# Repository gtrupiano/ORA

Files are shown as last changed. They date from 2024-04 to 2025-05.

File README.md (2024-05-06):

# Oakland Robotics Association (ORA)

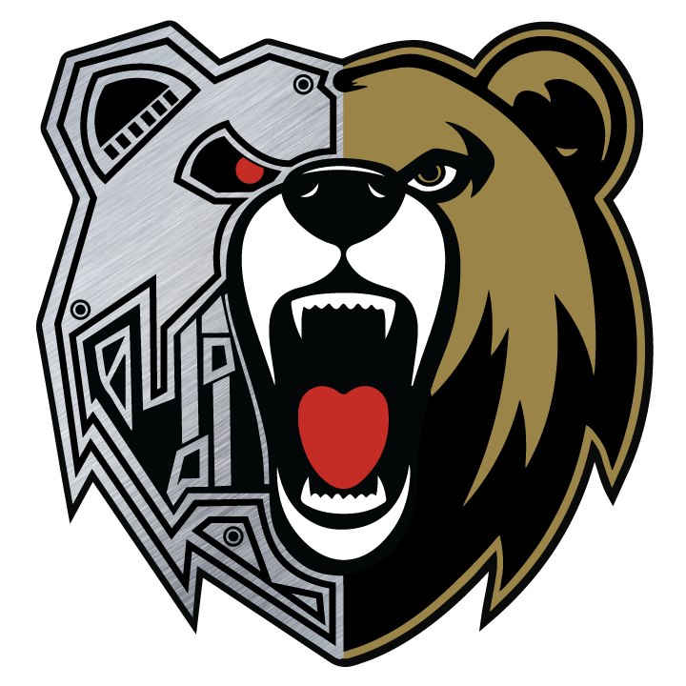
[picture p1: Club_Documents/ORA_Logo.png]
ORA


## IGVC
Each year, Robotics Association at Oakland University competes in the International Ground Vehicle
Competition (IGVC), specifically the IGVC auto-nav challenge. To compete, a fully autonomous
unmanned ground robotic vehicle needs to be design to travel around an outdoor obstacle course under a
prescribed time while maintaining certain speed constraints. The 2024 IGVC will take place at OU on
5/31/2024-6/3/2024. The Robotics Association will design a completely new robot for this year’s
competition.

### Electrical Subteam Requirements
The project looks to design, implement, and provide documentation for the electrical subsystem of the 2024
International Ground Vehicle Competition (IGVC) intelligent robotic platform. The project team will
interface with both mechanical and software subsystem teams to ensure smooth integration of the developed
electrical subsystem into the main robot. The electrical subsystem will include sensors (such as initial
measurement units, global positioning system, camera, etc.), motors, low-level controllers (such as
Arduino), power distribution system (including batteries, battery management systems, power converters,
etc.), LED display, and safety functions (such as emergency stops, fuses, and light indication). The project
will also involve detailed documentation and a final report that can be integrated into the IGVC final report.

## Components and Layout

### Control Board
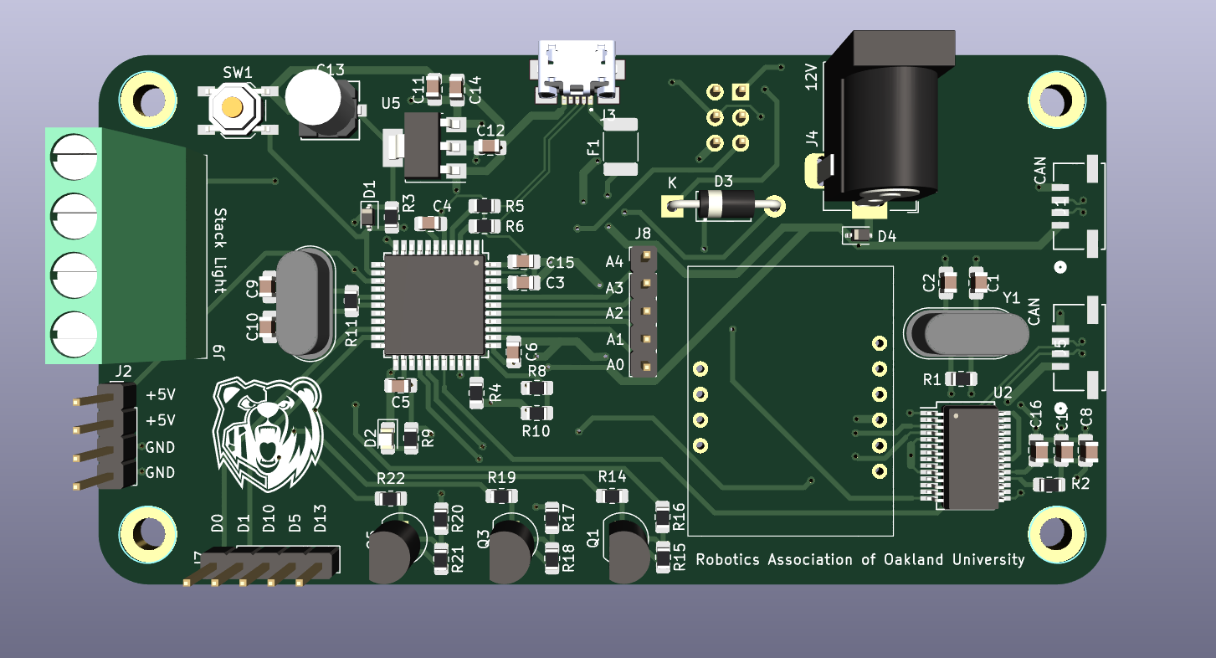
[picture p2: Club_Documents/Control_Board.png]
Control_Board


In the robot, there were plenty of components that needed to interface together. These include both ODrives over CAN and status light control. Its main purpose is to reduce the amount of wires that need to be going from each component and have every necessary component on a single board.

### Robot Control Layout
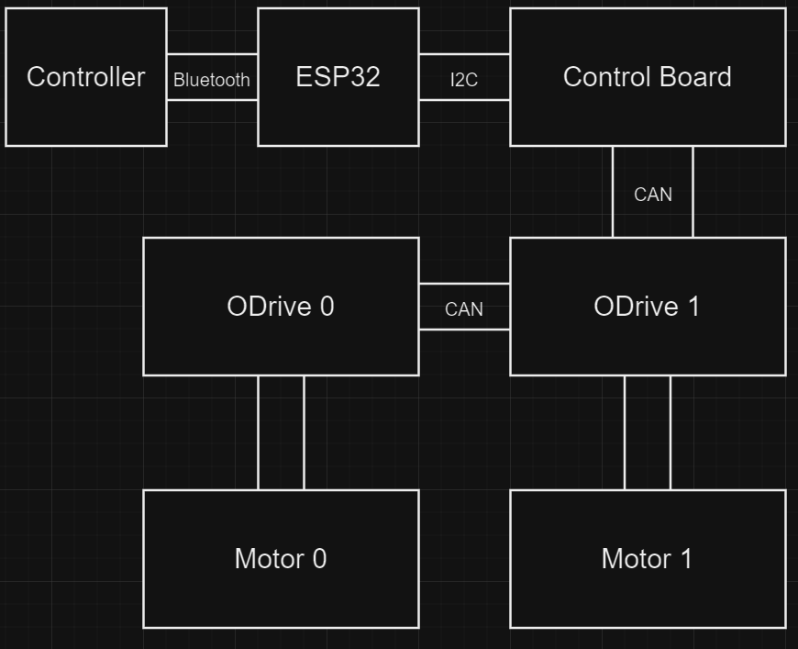
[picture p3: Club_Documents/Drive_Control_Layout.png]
Drive_Control


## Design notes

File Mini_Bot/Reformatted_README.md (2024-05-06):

# Oakland Robotics Association (ORA)

ORA Logo

## IGVC Competition Overview

Each year, the Robotics Association at Oakland University takes part in the International Ground Vehicle Competition (IGVC), focusing on the auto-nav challenge. In this competition, teams are tasked with designing a fully autonomous unmanned ground robotic vehicle capable of navigating an outdoor obstacle course within a set timeframe, while adhering to specified speed constraints. The 2024 IGVC is scheduled to be held at Oakland University from May 31 to June 3, 2024. Our team will develop an entirely new robot for this year's challenge.

### Electrical Subteam Goals

For the 2024 competition, our goal is to design, implement, and document the electrical subsystem of our intelligent robotic platform. This will involve collaboration with the mechanical and software subteams to ensure that the electrical components integrate seamlessly. The subsystem will feature a variety of components, including:
- Sensors (e.g., IMUs, GPS, cameras)
- Motors
- Low-level controllers (e.g., Arduino)
- Power distribution system (batteries, BMS, power converters, etc.)
- LED display
- Safety features (emergency stops, fuses, light indicators)

Detailed documentation and a comprehensive final report will be prepared to integrate into the IGVC final report.

## Design Components and Layout

### Control Board Overview

Control Board

The Control Board is designed to streamline the connections between various components, reducing the complexity of wiring and enhancing overall efficiency. Key features include integration of ODrives over CAN for motor control and management of the status light system. The board centralizes connections, making it easier to manage and troubleshoot the system.

### Robot Control Layout

Robot Drive Control Layout

This layout illustrates the schematic organization of the robot's driving and control systems. It highlights how different components interconnect and function together to provide optimal control and performance during competition.

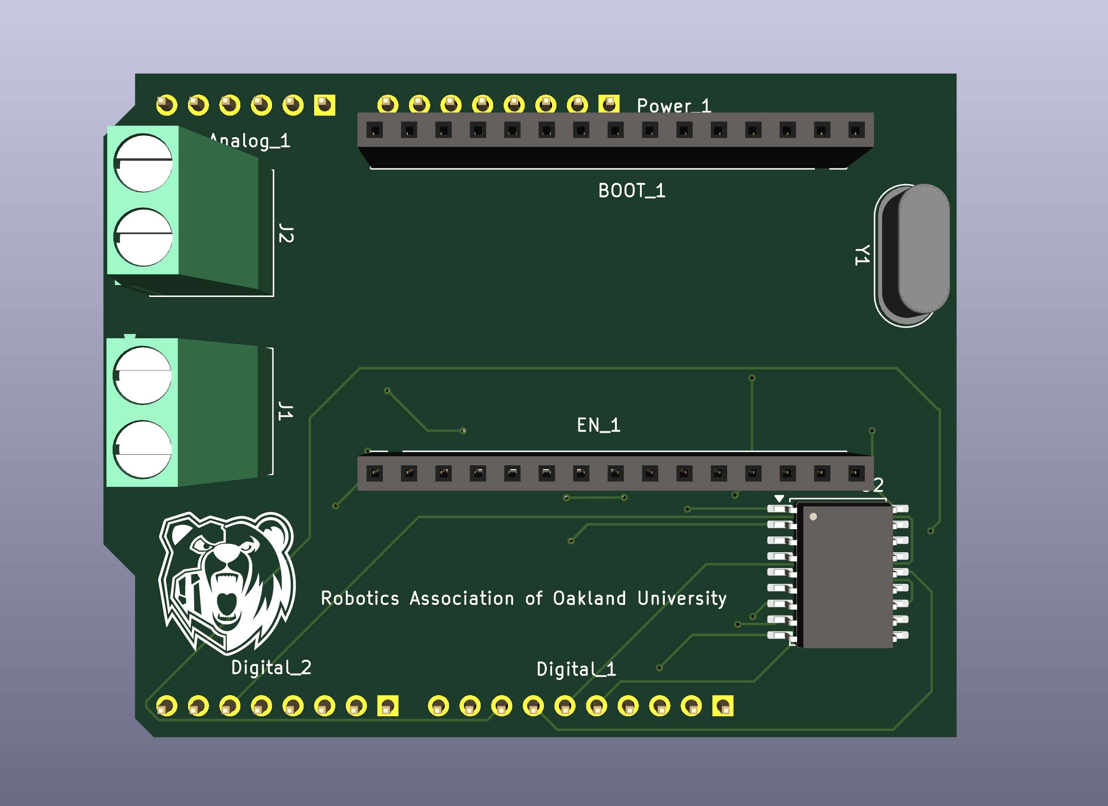
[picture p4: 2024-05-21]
Club_Documents/ESP_CAN_Shield_Front.png

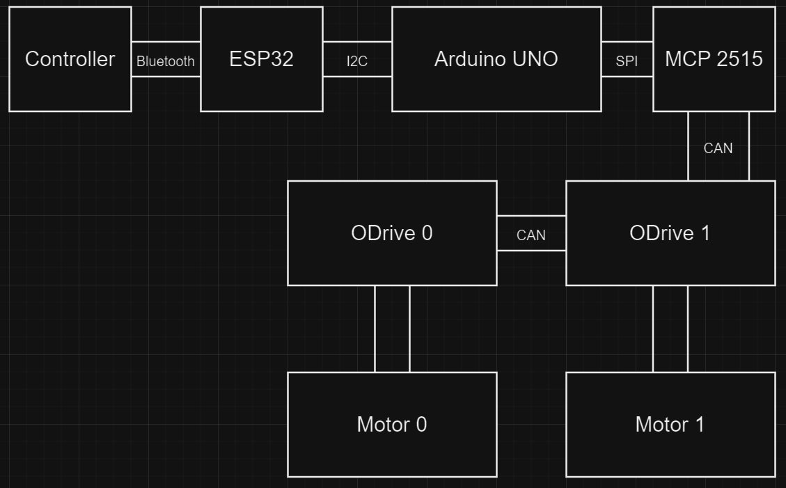
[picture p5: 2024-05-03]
Club_Documents/Drive_Control_Layout_Demo.png

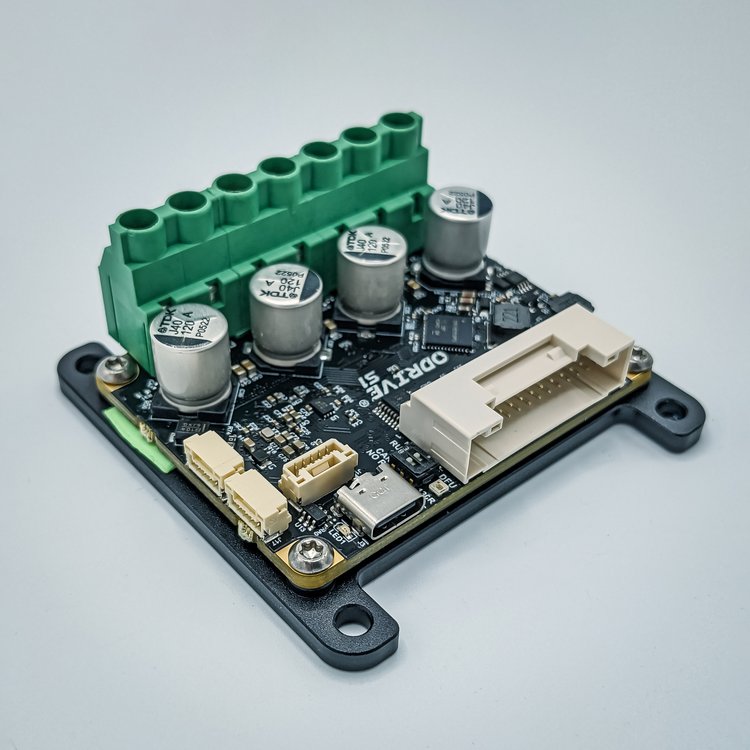
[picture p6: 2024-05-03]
Club_Documents/ODrive_S1.jpg

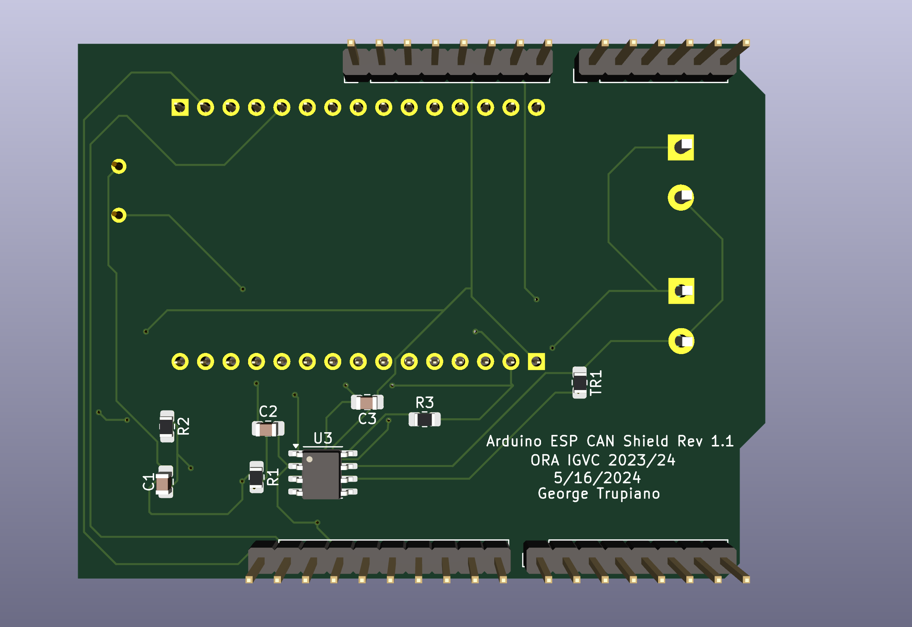
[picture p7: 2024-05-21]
Club_Documents/ESP_CAN_Shield_Back.png

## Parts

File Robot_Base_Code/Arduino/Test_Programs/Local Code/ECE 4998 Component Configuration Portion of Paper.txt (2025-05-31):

Since there are a variety of different components in Horizon, properly controlling each one is something that needs to be properly addressed. 

Components including each ODrive, CAN Communication with ODrive, Control Board, and Stack Light. Each component has both a software and hardware (wiring) aspect to it. 

ODrive
When configuring the ODrives, there were different perameters within the ODrive that needed to be configured. These include power, motor, control mode, and communication parameters.

	Power:
Configurations for the power supply needed to be modified based on the battery present on Horizon. Specifying the maximum and minimum voltage expected from the battery. This is used in order for the Odrive to check whtether it is being over or under volted and disengage when limits are crossed. 

Matching the specifications of the battery to the parameters, the maximum and minimum voltage shouldn't cross 17V and 12V respectivly. A maximum positive current is also needed to make sure the ODrive isn't drawing more current then possible from the battery which in this case is 30A.

	Motor:
Setting the motor parameters is needed to make sure the ODrives don't draw too much current from the battery. The parameters that are needed consist of pole pairs, KV, and current limit.

	Control Mode:
dsfaasdf

	Communication:
asdfasdf

CAN Communication with ODrive:

	Intro:
kjhgkjh

Connecting CAN signals to ODrive
ODriveArduino

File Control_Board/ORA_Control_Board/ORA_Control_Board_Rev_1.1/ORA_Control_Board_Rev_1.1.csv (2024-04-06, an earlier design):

Source: | C:\Users\sivas\Documents\Robotics\ORA_ControlBoard-main\ORA_ControlBoard-main\ORA_CONTROLBOARD_REV1\ORA_CONTROLBOARD_REV1.kicad_sch
Date: | 1/13/2024 3:55:22 PM
Tool: | Eeschema 7.0.8
Generator: | C:\Program Files\KiCad\7.0\bin\scripting\plugins/bom_csv_grouped_by_value_with_fp.py
Component Count: | 69
Ref | Qnty | Value | Cmp name | Footprint | Description | Vendor | DNP
C1, C2, C9, C10, C13 | 5 | 22uF | C_Polarized_Small | Capacitor_SMD:C_0805_2012Metric_Pad1.18x1.45mm_HandSolder | Polarized capacitor, small symbol
C3, C5, C6, C8, C14 | 5 | 100nF | C_Small | Capacitor_SMD:C_0805_2012Metric_Pad1.18x1.45mm_HandSolder | Unpolarized capacitor, small symbol
C4, C15 | 2 | 1uF | C_Small | Capacitor_SMD:C_0805_2012Metric_Pad1.18x1.45mm_HandSolder | Unpolarized capacitor, small symbol
C7 | 1 | 10uF | C_Small | Capacitor_SMD:C_0805_2012Metric_Pad1.18x1.45mm_HandSolder | Unpolarized capacitor, small symbol
C11 | 1 | 10nF | C_Small | Capacitor_SMD:C_0805_2012Metric_Pad1.18x1.45mm_HandSolder | Unpolarized capacitor, small symbol
C12 | 1 | 100uF | C_Small | Capacitor_SMD:C_0805_2012Metric_Pad1.18x1.45mm_HandSolder | Unpolarized capacitor, small symbol
D1 | 1 | rst | D_Small | Diode_SMD:D_0805_2012Metric_Pad1.15x1.40mm_HandSolder | Diode, small symbol
D2 | 1 | LED_Small | LED_Small | LED_SMD:LED_0805_2012Metric_Pad1.15x1.40mm_HandSolder | Light emitting diode, small symbol
D4 | 1 | PWRIN | D_Small | Diode_SMD:D_0805_2012Metric_Pad1.15x1.40mm_HandSolder | Diode, small symbol
D5 | 1 | IMU_LED | LED_Small | LED_SMD:LED_0805_2012Metric_Pad1.15x1.40mm_HandSolder | Light emitting diode, small symbol
F1 | 1 | MF-MSMF050-2 | Polyfuse_Small | Fuse:Fuse_1812_4532Metric_Pad1.30x3.40mm_HandSolder | Resettable fuse, polymeric positive temperature coefficient, small symbol
H1, H2, H3, H4 | 4 | MountingHole_Pad | MountingHole_Pad | MountingHole:MountingHole_3.2mm_M3_DIN965_Pad | Mounting Hole with connection
J1, J2, J5 | 3 | CAN | Screw_Terminal_01x02 | TerminalBlock_Phoenix:TerminalBlock_Phoenix_MKDS-1,5-2_1x02_P5.00mm_Horizontal | Generic screw terminal, single row, 01x02, script generated (kicad-library-utils/schlib/autogen/connector/)
J3 | 1 | USB_B_Micro | USB_B_Micro | Connector_USB:USB_Micro-B_Amphenol_10118194_Horizontal | USB Micro Type B connector
J4 | 1 | 12V | Barrel_Jack_MountingPin | Connector_BarrelJack:BarrelJack_Horizontal | DC Barrel Jack with a mounting pin
J6 | 1 | Conn_02x03_Top_Bottom | Conn_02x03_Top_Bottom | Connector_PinHeader_2.54mm:PinHeader_2x03_P2.54mm_Vertical | Generic connector, double row, 02x03, top/bottom pin numbering scheme (row 1: 1...pins_per_row, row2: pins_per_row+1 ... num_pins), script generated (kicad-library-utils/schlib/autogen/connector/)
J7, J8 | 2 | Conn_01x05_Pin | Conn_01x05_Pin | Connector_PinHeader_2.54mm:PinHeader_1x05_P2.54mm_Vertical | Generic connector, single row, 01x05, script generated
J9 | 1 | Stack Light | Screw_Terminal_01x04 | TerminalBlock_Phoenix:TerminalBlock_Phoenix_MKDS-1,5-4_1x04_P5.00mm_Horizontal | Generic screw terminal, single row, 01x04, script generated (kicad-library-utils/schlib/autogen/connector/)
Q1, Q3, Q5 | 3 | BS170 | NMOS | Package_TO_SOT_THT:TO-92_Inline | N-MOSFET transistor, drain/source/gate
Q2, Q4, Q6 | 3 | IRF9540N | PMOS | Package_TO_SOT_THT:TO-220-3_Vertical | P-MOSFET transistor, drain/source/gate
R1, R11 | 2 | 1M | R_Small | Resistor_SMD:R_0805_2012Metric_Pad1.20x1.40mm_HandSolder | Resistor, small symbol
R2, R3, R4, R12, R14, R15, R18, R19, R21, R22 | 10 | 10k | R | Resistor_SMD:R_0805_2012Metric_Pad1.20x1.40mm_HandSolder | Resistor
R5, R6 | 2 | 22 | R_Small | Resistor_SMD:R_0805_2012Metric_Pad1.20x1.40mm_HandSolder | Resistor, small symbol
R7, R9 | 2 | 470 | R_Small | Resistor_SMD:R_0805_2012Metric_Pad1.20x1.40mm_HandSolder | Resistor, small symbol
R8 | 1 | 2.2k | R | Resistor_SMD:R_0805_2012Metric_Pad1.20x1.40mm_HandSolder | Resistor
R10 | 1 | 1.57k | R | Resistor_SMD:R_0805_2012Metric_Pad1.20x1.40mm_HandSolder | Resistor
R13 | 1 | 120 | R_Small | Resistor_SMD:R_0805_2012Metric_Pad1.20x1.40mm_HandSolder | Resistor, small symbol
R16, R17, R20 | 3 | 1k | R | Resistor_SMD:R_0805_2012Metric_Pad1.20x1.40mm_HandSolder | Resistor
SW1 | 1 | Reset | SW_Push | Button_Switch_SMD:SW_SPST_TL3342 | Push button switch, generic, two pins
U1 | 1 | ATmega32U4-A | ATmega32U4-A | Package_QFP:TQFP-44_10x10mm_P0.8mm | 16MHz, 32kB Flash, 2.5kB SRAM, 1kB EEPROM, USB 2.0, TQFP-44
U2 | 1 | MCP2515-xSO | MCP2515-xSO | Package_SO:SOIC-18W_7.5x11.6mm_P1.27mm | Stand-Alone CAN Controller with SPI Interface, SOIC-18
U3 | 1 | MCP2551-I-SN | MCP2551-I-SN | Package_SO:SOIC-8_3.9x4.9mm_P1.27mm | High-Speed CAN Transceiver, 1Mbps, 5V supply, SOIC-8
U5 | 1 | NCP1117-5.0_SOT223 | NCP1117-5.0_SOT223 | Package_TO_SOT_SMD:SOT-223-3_TabPin2 | 1A Low drop-out regulator, Fixed Output 5V, SOT-223
U6 | 1 | IMU_MOUNT | IMU_MOUNT | Custom_Parts:IMU_MOUNT
Y1 | 1 | 8Mhz | Crystal | Crystal:Crystal_HC49-4H_Vertical | Two pin crystal
Y2 | 1 | 16MHz | Crystal | Crystal:Crystal_HC49-4H_Vertical | Two pin crystal

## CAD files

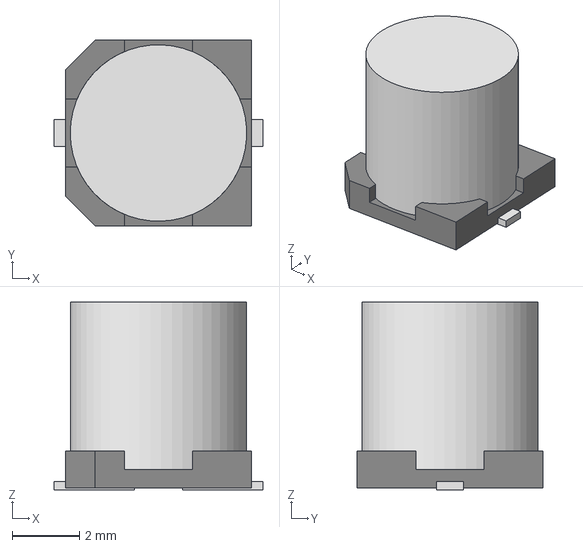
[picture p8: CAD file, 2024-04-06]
Control_Board/ORA_Control_Board/ORA_Control_Board_Rev_2.1/AdditionalParts/CAP_WCAP-ASLI_05p0X05p5_WRE.step
6.20 x 5.51 x 5.57 mm

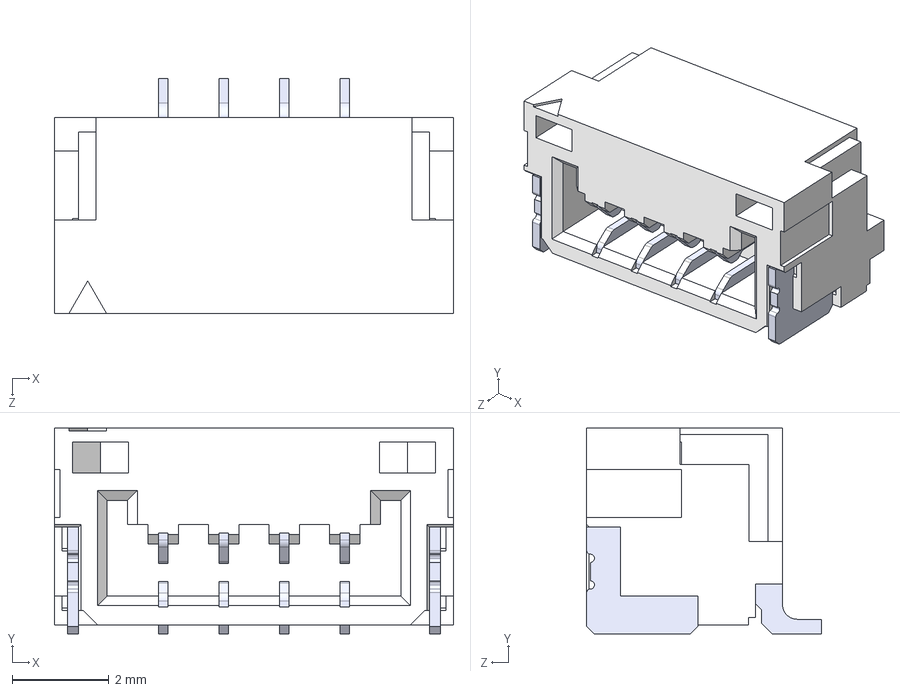
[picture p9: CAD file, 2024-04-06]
Control_Board/ORA_Control_Board/ORA_Control_Board_Rev_2.1/AdditionalParts/SM04B_GHS_TB/SM04B-GHS-TB.STEP
8.25 x 4.25 x 4.85 mm
SMxB-GHS-TB_04
pin x 4

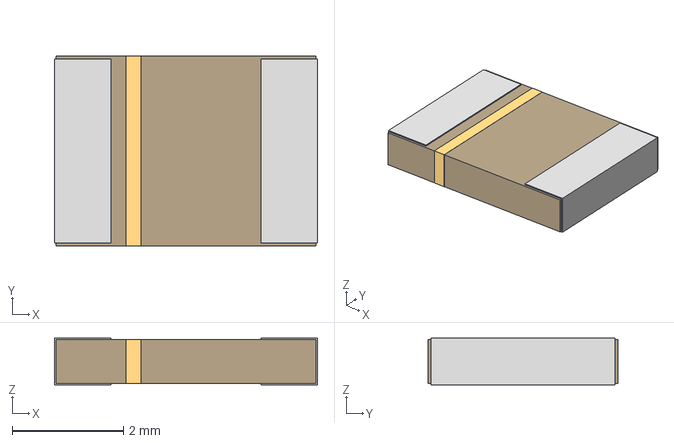
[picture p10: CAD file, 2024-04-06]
Control_Board/ORA_Control_Board/ORA_Control_Board_Rev_2.1/AdditionalParts/FUSE_F050-2.step
4.72 x 3.41 x 0.838 mm

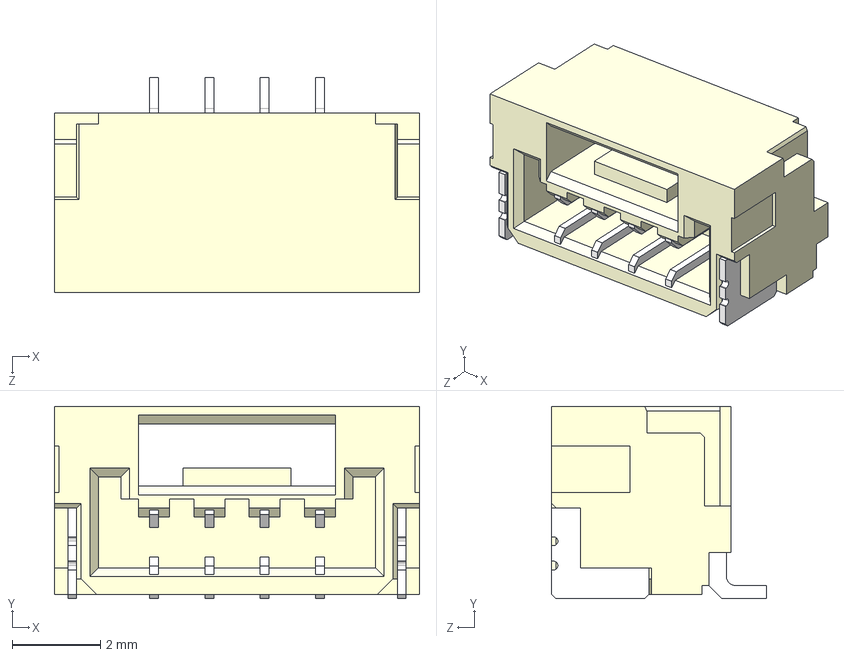
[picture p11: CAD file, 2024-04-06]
Control_Board/ORA_Control_Board/ORA_Control_Board_Rev_2.1/AdditionalParts/SM04B-GHS-TB(LF)(SN)---3DModel-STEP-56544.STEP
8.25 x 4.35 x 4.85 mm

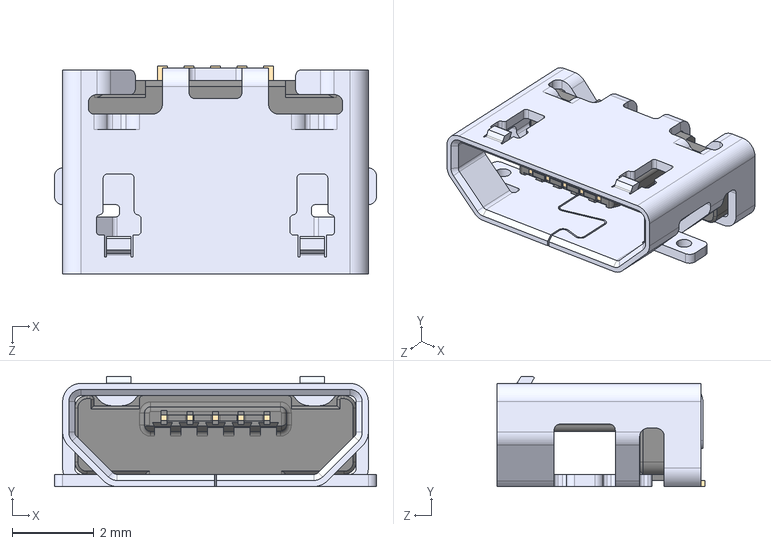
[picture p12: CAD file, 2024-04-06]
Control_Board/ORA_Control_Board/ORA_Control_Board_Rev_2.1/AdditionalParts/10118192_0002LF (1)/10118192-0002LF.step
7.90 x 2.70 x 5.10 mm

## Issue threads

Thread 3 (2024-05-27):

IGVC Preperations

gtrupiano, 2024-05-27:
- [ ] Add can messages for sending wheel speeds and autonomous state
- [ ] Hardware E-Stop
- [ ] Check controller disconnect fail save
- [ ] Look over Falling Edge Detection

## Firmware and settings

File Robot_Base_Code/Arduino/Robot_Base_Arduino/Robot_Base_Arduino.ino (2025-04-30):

#include "MCP2515.h"
#include "ODriveMCPCAN.hpp" // Includes ODriveCAN.h and MCP2515.h
#include <SPI.h>
#include <Wire.h>
#include <mcp_can.h>

#define CAN_BAUDRATE 500000
#define CAN0_INT 2 // This is the Interrupt pin
#define ODRV0_NODE_ID 0 // Left Motor
#define ODRV1_NODE_ID 1 // Right Motor

MCP2515Class& can_intf = CAN;

MCP_CAN CAN0(10);

#define MCP2515_CS 10
#define MCP2515_INT 2
#define MCP2515_CLK_HZ 8000000
#define EStop 8 // Hardware EStop

// Robot State Declarations
#define EStopButtonIndicator 1
#define AutonButtonIndicator 5

// Battery Voltage Detection Declaration
#define Battery_Voltage A0

// Physical perameters of robot
#define Wheel_Radius 0.184f // meters
#define Wheel_Seperation 0.7112f // meters
#define Max_Velocity 2.2352f //  Speed limit m/s according to IGVC rules

// Global Variable Declaration

// Controller Variables
int8_t angularMov = 0;
int8_t linearMov = 0;
bool EStopButton = false;
bool EStopState = false;
bool prevEStopButton = false;
bool AutonButton = false;
bool AutonState = false;
bool prevAutonButton = false;

// CAN IDs of the messages we are interested in
const unsigned long rightWheelSpeedID = 2;
const unsigned long leftWheelSpeedID = 3;
const unsigned long rightEncoderID = 4;
const unsigned long leftEncoderID = 5;
const unsigned long AutonStateID = 6;

// Buffers to store incoming CAN data
byte msgWheelSpeed[8];

// Variables to store wheel speeds
// They are delared as floats in the ODriveCAN library
float rightWheelSpeed;
float leftWheelSpeed;

// Variables to store encoder wheel speed 
// They are delared as floats in the ODriveCAN library
float odrv0EncoderVel; 
float odrv1EncoderVel;

// Function Prototypes
static inline void receiveCallback(int);
bool setupCan();
void onHeartbeat(Heartbeat_msg_t&, void*);
void onFeedback(Get_Encoder_Estimates_msg_t&, void*);
void onCanMessage(const CanMsg&);

// Data type created for ODrive (Consists of last heartbeat, if heartbeat was received, encoder feedback, and if there is feedback)
struct ODriveUserData 
{
  Heartbeat_msg_t last_heartbeat;
  bool received_heartbeat = false;
  Get_Encoder_Estimates_msg_t last_feedback;
  bool received_feedback = false;
};

// Initialize ODrive objects
ODriveCAN odrv0(wrap_can_intf(can_intf), ODRV0_NODE_ID); // Initalize odrv0 as ODriveCAN object with respective node ID
ODriveCAN odrv1(wrap_can_intf(can_intf), ODRV1_NODE_ID); // Initalize odrv1 as ODriveCAN object with respective node ID
ODriveCAN* odrives[] = {&odrv0, &odrv1}; // Make sure all ODriveCAN instances are accounted for here

// Initalizes variables to hold ODrive configuation data
ODriveUserData odrv0_user_data;
ODriveUserData odrv1_user_data;


void setup() 
{
  Serial.begin(115200);

  Wire.begin(8);

  pinMode(EStop, INPUT);

  pinMode(CAN0_INT, INPUT);

  pinMode(EStopButtonIndicator, OUTPUT);
  pinMode(AutonButtonIndicator, OUTPUT);

  pinMode(Battery_Voltage, INPUT);


  // Wait for up to 3 seconds for the serial port to be opened on the PC side
  for (int i = 0; i < 30 && !Serial; ++i) 
  {
    delay(100);
  }
  delay(200);

  // Register callbacks for the heartbeat and encoder feedback messages
  odrv0.onFeedback(onFeedback, &odrv0_user_data);
  odrv0.onStatus(onHeartbeat, &odrv0_user_data);

  odrv1.onFeedback(onFeedback, &odrv1_user_data);
  odrv1.onStatus(onHeartbeat, &odrv1_user_data);


  if (!setupCan()) 
  {
    Serial.println("CAN failed to initialize: reset required");
    while (true);
  }

  Serial.println("Waiting for ODrive...");
  while (!odrv0_user_data.received_heartbeat || !odrv1_user_data.received_heartbeat) 
  {
    pumpEvents(can_intf);
    delay(100);
  }

  Serial.println("ODrive Detected");

  // request bus voltage and current (1sec timeout)
  Serial.println("Attempting to read bus voltage and current");
  Get_Bus_Voltage_Current_msg_t vbus;
  if (!odrv0.request(vbus, 1)) 
  {
    Serial.println("vbus request failed!");
    while (true);
  }
  else if (!odrv1.request(vbus, 1))
  {
    Serial.println("vbus request failed!");
    while (true);
  }

  Serial.print("DC voltage [V]: ");
  Serial.println(vbus.Bus_Voltage);
  Serial.print("DC current [A]: ");
  Serial.println(vbus.Bus_Current);

  ODriveControlState();
  Serial.println("ODrive Setup Completed: ");
}

void loop() 
{
  // This is required on some platforms to handle incoming feedback CAN messages
  pumpEvents(can_intf);

  // Fetches values from controller that are sent over I2C
  fetchControllerData();

  // EStop Logic

  // Falling Edge Detection (Goes from High to Low)
  // EStop (If statement) only activates when button is pressed
  if (prevEStopButton == HIGH && EStopButton == LOW)
  {
    // Toggles EStop State
    // If state was off before then the action of pressing the button means that it is enabled
    if(!EStopState)
    {
      EStopState = true;
      Serial.println("EStop True");
    }

    else
    {
      EStopState = false;
      Serial.println("EStop False");
    }
  }
  
  prevEStopButton = EStopButton;
  

  if(EStopState)
  {
    ODriveEStop();
    digitalWrite(EStopButtonIndicator, HIGH);
  }
  else
  {
    ODriveControlState();
    ODriveMovement(angularMov, linearMov);
    digitalWrite(EStopButtonIndicator, LOW);
  }

  // Auton Logic

  // EStop has priority
  if(!EStopState)
  {
    // Falling Edge Detection (Goes from High to Low)
    // Auton (If statement) only activates when button is pressed
    if (AutonButton == LOW && prevAutonButton == HIGH)
    {
      // If state was off before then the action of pressing the button means that it is enabled
      if(!AutonState) 
      {
        AutonState = true;
      }
      
      else 
      {
        AutonState = false;
      }
    }
    prevAutonButton = AutonButton;
  }

  // Checks AutonState data (which is determined by the toggle of the controller button)
  if(AutonState)
  {
    autonMovement();
    digitalWrite(AutonButtonIndicator, HIGH);
    //Serial.println("Auton On");
  }
  else 
  {
    digitalWrite(AutonButtonIndicator, LOW);
    //Serial.println("Auton Off");
  }

  autonEncoderData();

  // Checks hardware EStop for light indication changes
  if(digitalRead(EStop) == LOW)
  {
    digitalWrite(EStopButtonIndicator, HIGH);
  } 

  else
  {
    digitalWrite(EStopButtonIndicator, LOW);
  }

  // Prints ODrive Velocities and Position via Encoders
  //ViewODriveEncoderData();  

  delay(50);
}

void fetchControllerData()
{
  // Requests data from slave device 8 (ESP32)
  Wire.requestFrom(8, sizeof(int8_t) + sizeof(int8_t) + sizeof(bool) + sizeof(bool));

  // Checks to see if data is recieved over I2C. If so sets values from controller to predefined variables
  if(Wire.available() >= sizeof(int8_t) + sizeof(int8_t) + sizeof(bool) + sizeof(bool))
  {
    // Read rotational movement from left joystick (Controller only sends 8 bit values)
    linearMov = Wire.read();

    // Read linear movement from left joystick
    angularMov = Wire.read();

    // Read EStopButton from right bumper (Controller only sends 8 bit values)
    EStopButton = Wire.read();

    // Read Robot State from left bumper
    AutonButton = Wire.read();
    
    // Reads controller values from ESP-32
    // ViewControllerData()
  } 
  else // make this engage estop
  {
    angularMov = 0;
    linearMov = 0;
    EStopState = true; // check if this logic makes sure if estop actually engages and doesn't mess up 
    AutonState = false;
    Serial.println("Insufficient bytes received");
  }
}

void ODriveMovement(int8_t angularVelIn, int8_t linearVelIn)
{
  // Normalize inputs to directional velocity vectors
  float angularVelocity = (float)angularVelIn / 127.0;
  float linearVelocity = (float)linearVelIn / 127.0;
  
  // Radians Per Second
  float leftMotorTPS = (1 / Wheel_Radius) * (linearVelocity - ((Wheel_Seperation * angularVelocity) / 2));
  float rightMotorTPS = (1 / Wheel_Radius) * (linearVelocity + ((Wheel_Seperation * angularVelocity) / 2));

  // Converting to Turns per second
  // Convert wheel speeds from rad/s to turns per second with scaling factor 21
  leftMotorTPS = (leftMotorTPS / (2 * M_PI)) * 21;
  rightMotorTPS = (rightMotorTPS / (2 * M_PI)) * -21;
  
  //Serial.println("Angular Velocity: " + (String) angularMov + "\tLinear Velocity: " + (String) linearMov + "\tLeft Motor: " + (String) leftMotorTPS + "\tRight Motor: " + (String) rightMotorTPS);
  
  // Send velocity CAN commands to left and right motors
  odrv0.setVelocity(leftMotorTPS);
  odrv1.setVelocity(rightMotorTPS);
}

// Sends command over CAN to ODrive to initiate EStop
void ODriveEStop()
{
  while (odrv0_user_data.last_heartbeat.Axis_State != ODriveAxisState::AXIS_STATE_IDLE || odrv1_user_data.last_heartbeat.Axis_State != ODriveAxisState::AXIS_STATE_IDLE) 
  {
    odrv0.clearErrors();
    delay(1);
    odrv0.setState(ODriveAxisState::AXIS_STATE_IDLE);

    odrv1.clearErrors();
    delay(1);
    odrv1.setState(ODriveAxisState::AXIS_STATE_IDLE);

    for (int i = 0; i < 15; ++i) 
    {
      delay(10);
      pumpEvents(can_intf); // Pump events for 150ms (Look at example for full explanation)
    }
  }
  Serial.println("EStop Activated");
}

// Send CAN command to put axis into closed loop control state
void ODriveControlState() 
{
  while (odrv0_user_data.last_heartbeat.Axis_State != ODriveAxisState::AXIS_STATE_CLOSED_LOOP_CONTROL || odrv1_user_data.last_heartbeat.Axis_State != ODriveAxisState::AXIS_STATE_CLOSED_LOOP_CONTROL) 
  {
    odrv0.clearErrors();
    delay(1);
    odrv0.setState(ODriveAxisState::AXIS_STATE_CLOSED_LOOP_CONTROL);

    odrv1.clearErrors();
    delay(1);
    odrv1.setState(ODriveAxisState::AXIS_STATE_CLOSED_LOOP_CONTROL);

    for (int i = 0; i < 15; ++i) 
    {
      delay(10);
      pumpEvents(can_intf);  // Pump events for 150ms (Look at example for full explanation)
    }
  }
  //Serial.println("Closed loop control state active");
}

// Prints position and velocity from each ODrive (For debugging)
void ViewODriveEncoderData()
{
  if (odrv0_user_data.received_feedback) 
  {
    Get_Encoder_Estimates_msg_t feedback = odrv0_user_data.last_feedback;
    odrv0_user_data.received_feedback = false;
    Serial.print("ODrive 0 Velocity:");
    Serial.println(feedback.Vel_Estimate);
    Serial.println("------------------------");
  }

  if (odrv1_user_data.received_feedback) 
  {
    Get_Encoder_Estimates_msg_t feedback = odrv1_user_data.last_feedback;
    odrv1_user_data.received_feedback = false;
    Serial.print("ODrive 1 Velocity:");
    Serial.println(feedback.Vel_Estimate);
    Serial.println("------------------------");
  }
}

// Prints received values of controller from ESP-32 (For debugging)
void ViewControllerData()
{
  Serial.print("Received from ESP32 - Angular Movement: ");
  Serial.println(angularMov);

  Serial.print("Received from ESP32 - Linear Movement: ");
  Serial.println(linearMov);

  Serial.print("Received from ESP32 - EStop Button: ");
  Serial.println(EStopButton);

  Serial.print("Received from ESP32 - Autonomous Button: ");
  Serial.println(AutonButton);

  Serial.println("------------------------");
}

void stateCommunication()
{
  byte AutonStateBA = (byte)AutonState;

  byte AutonStateMsgStatus = CAN0.sendMsgBuf(AutonStateID, 1, AutonStateBA);
}


// Receives data from path planner and send motor speeds to ODrives
void autonMovement() // Assuming data is given in rad/sec
{
  unsigned long receivedID;
  byte msgLen;

  // Check if a CAN messages are available (Now looks for all messages in the bus rather than just per function call)
  while(CAN_MSGAVAIL == CAN0.checkReceive()) 
  {
    // Read the CAN messages in the RX buffer
    CAN0.readMsgBuf(&receivedID, &msgLen, msgWheelSpeed);
    
    if(msgLen == 8)
    {
      // Check if the received message ID matches the right wheel speed ID
      if(receivedID == rightWheelSpeedID)
      {
        memcpy(&rightWheelSpeed, msgWheelSpeed, sizeof(float));
      }

      // Check if the received message ID matches the left wheel speed ID
      else if(receivedID == leftWheelSpeedID)
      {
        memcpy(&leftWheelSpeed, msgWheelSpeed, sizeof(float));
      }

    }
    else 
    {
      Serial.println("Received message length does not match expected float size.");
    }
  }

  leftWheelSpeed = (leftWheelSpeed / ((float)(2f * M_PI))) * 21f;
  rightWheelSpeed = (rightWheelSpeed / ((float)(2f * M_PI))) * -21f;
  
  odrv0.setVelocity(leftWheelSpeed);
  odrv1.setVelocity(rightWheelSpeed);
}

// Obtains Encoder data from each ODrive and sends it over CAN to it's respective ID
void autonEncoderData()
{
  // Obtaining ODrive Encoder data
  if (odrv0_user_data.received_feedback) 
  {
    Get_Encoder_Estimates_msg_t feedbackOdrv0 = odrv0_user_data.last_feedback;
    odrv0EncoderVel = feedbackOdrv0.Vel_Estimate;
    odrv0_user_data.received_feedback = false;
  }

  if (odrv1_user_data.received_feedback) 
  {
    Get_Encoder_Estimates_msg_t feedbackOdrv1 = odrv1_user_data.last_feedback;
    odrv1EncoderVel = feedbackOdrv1.Vel_Estimate;
    odrv1_user_data.received_feedback = false;
  }

  // Sending that data over CAN using left and right wheel IDs

  // leftWheelSpeedID,  ODrv 0 is the left wheel
  // rightWheelSpeedID, ODrv 1 is the right wheel
  
  byte* odrv0EncoderVelBA = (byte*)&odrv0EncoderVel;
  byte* odrv1EncoderVelBA = (byte*)&odrv1EncoderVel;
  

  byte leftMsgStatus = CAN0.sendMsgBuf(leftEncoderID, 4, odrv0EncoderVelBA); // length might be incorrect.
  byte rightMsgStatus = CAN0.sendMsgBuf(rightEncoderID, 4, odrv1EncoderVelBA);

  // Check the feedback message to see if the message was sent successfully (was the message acknowledged)
  if (leftMsgStatus != CAN_OK) 
  {
    Serial.println("Error Sending Left Encoder Data...");
  }

  if (rightMsgStatus != CAN_OK) 
  {
    Serial.println("Error Sending Right Encoder Data...");
  }
  else
  {
    //Serial.println("Message Sent Successfully!");
  }
}

// Below are all of the ODriveCAN Specific function declarations

static inline void receiveCallback(int packet_size)
{
  if (packet_size > 8) 
  {
    return;
  }
  CanMsg msg = {.id = (unsigned int)CAN.packetId(), .len = (uint8_t)packet_size};
  CAN.readBytes(msg.buffer, packet_size);
  onCanMessage(msg);
}

// Configure and initialize the CAN bus interface
bool setupCan() 
{
  if(CAN0.begin(MCP_ANY, CAN_500KBPS, MCP_8MHZ) == CAN_OK) // Should this be MCP_Normal?
  {
    Serial.println("MCP2515 Initialized Successfully!");
  }
  else
  {
    Serial.println("Error Initializing MCP2515...");
  }
  
  CAN0.setMode(MCP_NORMAL); // Should this be MCP_Any?


  CAN.setPins(MCP2515_CS, MCP2515_INT);
  CAN.setClockFrequency(MCP2515_CLK_HZ);
  if (!CAN.begin(CAN_BAUDRATE))
  {
    return false;
  }

  CAN.onReceive(receiveCallback);
  return true;
}

// Called every time a Heartbeat message arrives from the ODrive
void onHeartbeat(Heartbeat_msg_t& msg, void* user_data) 
{
  ODriveUserData* odrv_user_data = static_cast<ODriveUserData*>(user_data);
  odrv_user_data->last_heartbeat = msg;
  odrv_user_data->received_heartbeat = true;
}

// Called every time a feedback message arrives from the ODrive
void onFeedback(Get_Encoder_Estimates_msg_t& msg, void* user_data) 
{
  ODriveUserData* odrv_user_data = static_cast<ODriveUserData*>(user_data);
  odrv_user_data->last_feedback = msg;
  odrv_user_data->received_feedback = true;
}

// Called for every message that arrives on the CAN bus
void onCanMessage(const CanMsg& msg) 
{
  for (auto odrive: odrives) 
  {
    onReceive(msg, *odrive);
  }

}

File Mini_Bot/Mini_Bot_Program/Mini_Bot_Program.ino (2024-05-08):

#include <ps5Controller.h>

#include "soc/soc.h"
#include "soc/rtc_cntl_reg.h"

const char macAddress[] = "d0:bc:c1:fc:a1:84";

const int deadband = 5;

const int motorFL = 2;
const int motorFR = 14;
const int motorBL = 19;
const int motorBR = 32;

const int dirFL = 4;
const int dirFR = 12;
const int dirBL = 21;
const int dirBR = 33;

int speedY = 0, speedX = 0, rotation = 0;

void setup() 
{
  Serial.begin(921600);
  ps5.begin(macAddress);

  pinMode(dirFL, OUTPUT);
  pinMode(dirFR, OUTPUT);
  pinMode(dirBL, OUTPUT);
  pinMode(dirBR, OUTPUT);

  pinMode(motorFL, OUTPUT);
  pinMode(motorFR, OUTPUT);
  pinMode(motorBL, OUTPUT);
  pinMode(motorBR, OUTPUT);

  Serial.println("Ready");
}

void loop() 
{
  while (ps5.isConnected() == true) 
  {
    int joystickX = ps5.LStickX();
    int joystickY = ps5.LStickY();
    int rotatestick = ps5.RStickX();

    Serial.println(joystickX);
    Serial.println(joystickY);
    Serial.println(rotatestick);
    Serial.println("---");


    speedX = (abs(joystickX) > deadband) ? map(joystickX, -128, 127, -255, 255) : 0;
    speedY = (abs(joystickY) > deadband) ? map(joystickY, -128, 127, -255, 255) : 0;
    rotation = (abs(rotatestick) > deadband) ? map(rotatestick, -128, 127, -255, 255) : 0;
    
    mecanumDrive(speedX, speedY, rotation);
    delay(10);
  }
}

void setMotorSpeedAndDirection(int motorPin, int dirPin, int speed, int direction) 
{
  speed = constrain(speed, 0, 255);
  digitalWrite(dirPin, direction);
  analogWrite(motorPin, speed);
}

void mecanumDrive(int x, int y, int rotation) 
{
  int FL_speed = y + x + rotation;
  int FR_speed = y - x - rotation;
  int BL_speed = y - x + rotation;
  int BR_speed = y + x - rotation;

  int maxSpeed = max(max(abs(FL_speed), abs(FR_speed)), max(abs(BL_speed), abs(BR_speed)));

  if (maxSpeed > 255) 
  {
    FL_speed = map(FL_speed, -maxSpeed, maxSpeed, -255, 255);
    FR_speed = map(FR_speed, -maxSpeed, maxSpeed, -255, 255);
    BL_speed = map(BL_speed, -maxSpeed, maxSpeed, -255, 255);
    BR_speed = map(BR_speed, -maxSpeed, maxSpeed, -255, 255);
  }

  setMotorSpeedAndDirection(motorFL, dirFL, abs(FL_speed), FL_speed >= 0 ? HIGH : LOW);
  setMotorSpeedAndDirection(motorFR, dirFR, abs(FR_speed), FR_speed >= 0 ? HIGH : LOW);
  setMotorSpeedAndDirection(motorBL, dirBL, abs(BL_speed), BL_speed >= 0 ? HIGH : LOW);
  setMotorSpeedAndDirection(motorBR, dirBR, abs(BR_speed), BR_speed >= 0 ? HIGH : LOW);
}

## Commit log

2024-03-19 Update Robot_Base_Code_MCP_2_Good__.ino
    Toggle function for E-Stop implemented
    Movement function adjusted for revolutions per second calculations.
    Declarations done for IMU, LED, etc.
2024-03-21 Made separate program for Control board and ESP32
2024-03-23 Basic I2C programs created
    This was just to test whether inputs from controller could be received from ESP and transmitted through I2C to a separate Arduino.
2024-03-28 Working I2C program
    Controller values are able to be received from ESP and sent to arduino uno.
2024-03-29 Finished testing I2C programs
2024-03-29 Added proper I2C communication
2024-04-03 Added control board and reformatting
    [10118192-0002LF.step, CAN_Circuit.kicad_sch, CAP_WCAP-ASLI_05p0X05p5_WRE.step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]
2024-04-06 Created Robot Base Code using ODriveArduino Library
    Original MCP program was modified to incorperate ODriveArduino Library
2024-04-07 Modified receive program
    ESP is being weird but arduino 2 arduino works for I2C
2024-04-21 Made rev 2.1
    Still need rev 2
    [10118192-0002LF.step, CAP_WCAP-ASLI_05p0X05p5_WRE.step, FUSE_F050-2.step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]
2024-04-21 Rev 2
    [10118192-0002LF.step, CAN_Circuit.kicad_sch, CAP_WCAP-ASLI_05p0X05p5_WRE.step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]
2024-05-07 Created new program that incorperates both motors
    Need to fix math for differential drive and variable names.
    Also test if both motors can be controlled using the logic that is set up.
    (setup function)
    [Robot_Base_Arduino_One_Motor.ino]
2024-05-07 Created new programs for testing dual motor control
2024-05-12 Created Arduino ESP Shield
    [ORA_Arduino_ESP_Shield.kicad_pcb, ORA_Arduino_ESP_Shield.kicad_sch]
2024-05-13 Created ESP_CAN Shield and "Finished" ESP Shield
    [ORA_Arduino_ESP_CAN_Shield.kicad_pcb, ORA_Arduino_ESP_CAN_Shield.kicad_sch, ORA_Arduino_ESP_Shield.kicad_pcb]
2024-05-13 CAN Shield finished
    [ORA_Arduino_ESP_CAN_Shield.kicad_pcb, ORA_Arduino_ESP_CAN_Shield.kicad_sch]
2024-05-15 Finalizing board for ordering
    [ORA_Arduino_ESP_CAN_Shield-B_Cu.gbr, ORA_Arduino_ESP_CAN_Shield-B_Mask.gbr, ORA_Arduino_ESP_CAN_Shield-B_Paste.gbr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]
2024-05-16 Final Revision of ESP and CAN shield
    [ORA_Arduino_ESP_CAN_Shield-B_Cu.gbr, ORA_Arduino_ESP_CAN_Shield-B_Mask.gbr, ORA_Arduino_ESP_CAN_Shield-B_Paste.gbr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]
2024-05-17 Fixed issue with pin spacing and added revision that was ordered
    [ORA_Arduino_ESP_CAN_Shield-B_Cu.gbr, ORA_Arduino_ESP_CAN_Shield-B_Mask.gbr, ORA_Arduino_ESP_CAN_Shield-B_Paste.gbr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]
2024-05-22 Created Rev 2 with Stack light terminals
    [ORA_Arduino_ESP_CAN_Shield_Rev_2.kicad_pcb, ORA_Arduino_ESP_CAN_Shield_Rev_2.kicad_sch]
2024-05-23 Fixed errors in rev 1
    Issues include:
    misplaced esp pins, moved capacitor
    Improvements:
    Used proper footprints for ESP as well as arduino
    [ORA_Arduino_ESP_CAN_Shield_Rev_1.2.kicad_pcb, ORA_Arduino_ESP_CAN_Shield_Rev_1.2.kicad_sch, ORA_Arduino_ESP_CAN_Shield_Rev_2.kicad_pcb]
2024-05-23 Fixed footprint issues for ESP
    Things to fix:
    Route CAN as differential pairs (How to split the pair)
    [ORA_Arduino_ESP_CAN_Shield_Rev_2.kicad_pcb]
2024-05-23 Fixed and ordered rev 1.1
    [ORA_Arduino_ESP_CAN_Shield_Rev_1.1-B_Cu.gbr, ORA_Arduino_ESP_CAN_Shield_Rev_1.1-B_Mask.gbr, ORA_Arduino_ESP_CAN_Shield_Rev_1.1-B_Paste.gbr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]
2024-05-27 Gerber Files
    [ORA_Arduino_ESP_CAN_Shield_Rev_1.2.kicad_sch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]
2024-05-27 Fixed CAN IC Issues
    Changed oscillator capacitor values to 22pF, corrected reset for 2515 as active low (connected to 5V)
    [ORA_Arduino_ESP_CAN_Shield_Rev_1.1.kicad_pcb, ORA_Arduino_ESP_CAN_Shield_Rev_1.1.kicad_sch]
2024-05-27 Applied all legacy updates with CAN ICs from rev 1 to 1.2 and 2
    [ORA_Arduino_ESP_CAN_Shield_Rev_1.2.kicad_pcb, ORA_Arduino_ESP_CAN_Shield_Rev_1.2.kicad_sch, ORA_Arduino_ESP_CAN_Shield_Rev_2.kicad_pcb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]
2024-05-27 Made separate files for Rev 1.1 and Rev 1.15
    Rev 1.1 (which was ordered) had an error with the reset pin on the mcp 2515 chip. It should have been active low and not active high.
    Rev 1.15 has this issue fixed but isn't ordered
    [ORA_Arduino_ESP_CAN_Shield_Rev_1.15-B_Cu.gbr, ORA_Arduino_ESP_CAN_Shield_Rev_1.15-B_Mask.gbr, ORA_Arduino_ESP_CAN_Shield_Rev_1.15-B_Paste.gbr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]
2024-05-27 Update Robot_Base_Arduino.ino
    Add the sending of autonomous state and add physical estop button logic (it should override the software estop aka, it should be the first and main determiner for whether the robot is in an estop sta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
2024-05-29 Added Rev 1.1 for control board
    [CAN_Circuit.kicad_sch, IMUCONN_sch.kicad_sch, ORA_Control_Board_Rev_1.1.csv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]
2024-05-29 Updated Rev 1.1 for control board
    [ORA_Control_Board_Rev_1.1.kicad_pcb]
2024-06-04 Fixed Auton Issues and Debugging CAN Communication
    MCP Chip only allows 2 messages to be received at one time. Might try to do fifo or send the CAN messages directly from the ODrives
    [ODrive_User_Input_CAN_Encoder_Send.ino, Robot_Base_Arduino.ino]
2025-01-21 New unified program
    Making unified program that only uses ESP32
2025-04-30 Made changes to data types for speeds and encoder data in order to match the library. Also, made changes to autonomous mode function to check all messages in the RX buffer and not just one message.
